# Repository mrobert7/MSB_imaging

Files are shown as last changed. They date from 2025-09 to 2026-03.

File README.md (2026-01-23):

# LOTUS: A low-cost time-lapse automated imaging system for spatio-temporal analysis of microbial colony or biofilm development



## Overview

LOTUS is an open-source automated biofilm imaging platform built using Raspberry Pi, 3D-printed components, and motorized sample positioning. This repository contains all necessary files, scripts, and documentation to build and operate your own LOTUS system for macro-scale bacterial biofilm research.

Published in: *PLOS ONE* - Sakai et al. (2026)

LOTUS provides a cost-effective alternative to expensive commercial imaging systems while maintaining sufficient capability for spatio-temporal analysis of bacterial biofilm development and gene expression dynamics. The system is designed for:

- **Biofilm heterogeneity studies** - Track spatial and temporal patterns in biofilm development
- **Fluorescence reporter imaging** - Monitor gene expression using GFP, mCherry, and other fluorescent proteins
- **Multimode imaging** - Brightfield, transparency (biomass proxy), and fluorescence dual-reporter experiments
- **Time-lapse studies** - Automated long-term imaging with minimal user intervention
- **Educational applications** - Accessible platform for teaching microbiology and bioengineering

## Key Features

- **Low-cost construction:** Build for a fraction of commercial system costs
- **Automated sample positioning:** Motorized stage for multi-sample experiments
- **Fluorescence imaging:** Optimized for common fluorescent reporters (GFP, mCherry)
- **Open-source design:** All hardware designs, software, and analysis tools freely available
- **Validated performance:** Peer-reviewed characterization of sensitivity SNR, channel cross-talk, and phototoxicity
- **Flexible and modular:** Customize for your specific research needs

## Repository Contents

### 📁 [3D_printed_parts_stl_file](./3D_printed_parts_stl_file)
STL files for all custom 3D-printed components including:
- Sample stage
- Camera mounts
- LED housing
- Motorized positioning components

### 📁 [3D_printer_parameter](./3D_printer_parameter)
Recommended printing parameters and settings for optimal part quality and functionality.

### 📁 [Setting up LOTUS](./Setting%20up%20LOTUS)
Complete setup documentation including:
- Hardware assembly instructions
- Raspberry Pi configuration
- Software installation
- System calibration procedures

### 📁 [Experimental_script_imaging_operation](./Experimental_script_imaging_operation)
Python scripts for:
- Automated image acquisition
- Time-lapse control
- Multi-sample positioning
- Fluorescence excitation control

### 📁 [Image_Analysis](./Analysis_imageJ)
ImageJ macros and workflows for:
- Image preprocessing
- Biofilm biomass quantification
- Fluorescence intensity analysis
- Time-series data processing

### 📁 [Supervisor](./Supervisor)
System monitoring and management tools:
- Process supervision
- Automated restart functionality
- Error logging and recovery

### 📁 [Supplementary material_video](./Supplementary%20material_video)
Demonstration videos showing:
- System operation
- Biofilm time-lapse examples
- Setup procedures

## System Capabilities

### Validated Performance Metrics

- **Detection sensitivity:** Quantitative detection of fluorescent reporter expression
- **Temporal resolution:** Configurable image acquisition intervals (minutes to hours)
- **Spatial coverage:** Multiple biofilm colonies per experiment
- **Photobleaching characterization:** Minimal signal degradation over extended imaging
- **Signal-to-noise ratio:** Sufficient for semi-quantitative gene expression analysis
- **Channel cross-talk:** Validated for dual-reporter experiments (GFP/mCherry)
- **Phototoxicity assessment:** Safe for bacterial biofilm viability

## Citation

If you use LOTUS in your research, please cite:

> Sakai, M., et al. (2026). LOTUS: A low-cost open-source automated biofilm imaging system for spatio-temporal analysis of bacterial gene expression. *PLOS ONE*. DOI: [10.1371/journal.pone.0339652](https://journals.plos.org/plosone/article?id=10.1371/journal.pone.0339652)

## Comparison to Commercial Systems

| Feature | LOTUS | Commercial Systems |
|---|---|---|
| Cost | < $550 | $10,000 - $100,000+ |
| Application | Macro-scale screening | Single-cell to macro |
| Resolution | Semi-quantitative | High-resolution quantitative |
| Throughput | Multi-sample (configurable) | Varies |
| Customization | Fully open-source | Limited |
| Best for | Budget-conscious labs, experimenting, education, screening | Detailed mechanistic studies |

LOTUS is designed to **complement** rather than replace commercial systems, providing an accessible entry point for biofilm research.

## Contributing

We welcome contributions from the community! Please consider:

- Reporting bugs or issues
- Suggesting enhancements
- Sharing your modifications or improvements
- Contributing analysis tools or scripts
- Documenting your experiences

Please open an issue or submit a pull request on GitHub.

## Support and Contact

- **Issues:** Use GitHub Issues for bug reports and technical questions
- **Discussions:** Share your experiences and ask questions in GitHub Discussions
- **Email:** [robert.martin.4m@kyoto-u.ac.jp]

## License

You are free to:
- Use LOTUS for academic or commercial purposes
- Modify and distribute the design
- Build upon this work

We only ask that you:
- Provide attribution (cite our paper)
- Share improvements with the community

## Acknowledgments

We thank the open-source hardware community for inspiration and the microbiology research community for valuable feedback during development.

Special thanks to:
- PLOS ONE reviewers for thorough feedback that improved the system
- Colleagues and MSB lab beta testers at Kyoto University who provided validation data
- The Raspberry Pi Foundation for accessible computing platforms

## Additional Resources

- **PLOS ONE publication:** [Link to paper](https://journals.plos.org/plosone/article?id=10.1371/journal.pone.0339652)
- **Supplementary Information:** Detailed validation protocols and additional data
- **Video demonstrations:** See `Supplementary material_video/`
- **Community forum:** [TBA]

---

**LOTUS** - Making biofilm research accessible to all laboratories, regardless of budget.

For questions, collaborations, or to share your LOTUS builds, please reach out!

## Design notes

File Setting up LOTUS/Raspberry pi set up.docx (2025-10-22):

I. Raspberry pi setup
1. Install and launch Raspberry pi imager from web site to your computer

(https://www.raspberrypi.com/software/)

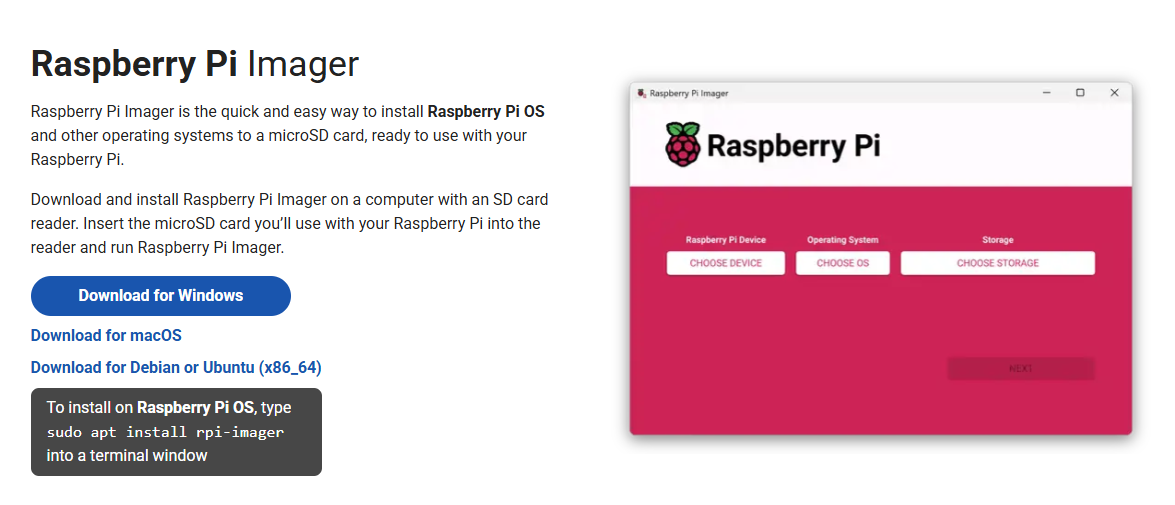
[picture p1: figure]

2. Download Legacy OS (https://downloads.raspberrypi.com/raspios_oldstable_armhf/images/raspios_oldstable_armhf-2024-03-12/) and write Raspberry pi OS (Legacy) to SD card
3. Install SD card to Raspberry pi board
4. Connect keyboard, mouse and display to Raspberry pi board
5. Turn Raspberry pi ON
6. Setup nationality, language, user name, password and wifi connection
7. Shutdown and remove mouse, keyboard and display
8. Turn Raspberry pi ON, When desktop is available, Connect your computer to Raspberry pi remotely using via VNC viewer (Need to enter IP address, user name and password in advance) (Download VNC Viewer by RealVNC® (https://www.realvnc.com/en/connect/download/viewer/?lai_sr=5-9&lai_sl=l))
9. To stabilize network connection, Parameter is change in network preference

Configure : wlan0

□Automatically configure empty option

☑ Disable IPv6

IPv4 Address : Raspberry pi IP address

Please fill the Router, DNS servers and DNS search items.

Check list

□Can you connect to Raspberry pi using VNC?

II. Supervisor application
1. In linux terminal, enter “ sudo apt-get install supervisor “
2. In linux terminal, enter “ cd /etc/supervisor “
3. In linux terminal, enter “ ls “
4. Update permissions for all files listed using “ sudo chmod 777 supervisord.conf “
5. Update permissions for all files listed using “ sudo chmod -R 777 conf.d “
6. Open file manager and enter “ /etc/supervisor “ at directory
7. Rewrite the contents of supervisord.conf to the same context as attached folder and save it. supervisord.conf file directory : " https://github.com/mrobert7/MSB_imaging/blob/main/Supervisor/supervisord.conf "
8. Create a file named “ CU.conf ” in the conf.d folder, paste the contents of the attached CU.conf and save it. (Use the username set on the Raspberry pi.)

CU.conf file directory : " https://github.com/mrobert7/MSB_imaging/blob/main/Supervisor/conf.d/CU.conf "

9. Create a folder in home/pi with the name Experiment and create files in the folder with the names “ CU.py ” and “ CU.log ”.
10. In linux terminal, enter “ pip3 install ischedule “
11. Reboot
12. Check to see if any errors are identified when executing “ sudo supervisorctl status CU:CU.py ” in linux terminal.

Check list

□Is “CU.py” executable in Supervisor?

III. Setup Camera module
1. In linux terminal, enter “ sudo geany “
2. Open boot/config.txt file by geany and write “ dtoverlay=arducam-64mp “ at the bottom of the script in the config.txt file (16mp→imx519)

Please check→ https://docs.arducam.com/Raspberry-Pi-Camera/Native-camera/Quick-Start-Guide/#cm3cm4

3. In linux terminal, enter “ wget -O install_pivariety_pkgs.sh https://github.com/ArduCAM/Arducam-Pivariety-V4L2-Driver/releases/download/install_script/install_pivariety_pkgs.sh “
4. In linux terminal, enter “ chmod +x install_pivariety_pkgs.sh “
5. In linux terminal, enter “ ./install_pivariety_pkgs.sh -p libcamera_dev “
6. In linux terminal, enter “ ./install_pivariety_pkgs.sh -p libcamera_apps “
7. Reboot
8. To check camera operation, in terminal, enter “ libcamera-hello “

(Please check whether camera is accurately connected to pi computer)

Check list

□Is the camera working?

IV. Ready for experiment script
1. Make a “ slotimaging “ folder in the new USB .
2. Make a “ Data “ folder in the “ slotimaging “ folder .
3. Create a “ well1 “ “ well2 ““ well3 ““ well4 ““ well5 ““ well6 ““ well7 ““ well8 ““ well9 “folder in the “ Data “ folder in the USB.
4. Create a “ Data1 “ “ Data2 ““ Data3 ““ Data4 “folder in the each well folder.
5. Download all sh files to Experiment folder

sh file directory : https://github.com/mrobert7/MSB_imaging/tree/main/Experimental_script_imaging_operation "

※Rewrite the contents of sh file to use as an imaging parameter script.

Example (White trans image)

libcamera-still

--width 2312 # Width pixel of captured image

--height 1736 # height pixel of captured image

--datetime -n -o /media/raspberry4/Raspi_USB/slotimaging/well1/Data1 # Directory to destination folder

--contrast 1.0 # Image contrast

--brightness 0.1 # Image brightness

--shutter 500 # Shutter speed (unit is µs)

--autofocus-mode manual # Manual focus

--lens-position 13 # Focus adjustment

--awbgains 1.5,2.0　#RGB

--lens position 14

6. Rewrite contents of “ CU.py “ to the same context as attached folder and save it

※Rewrite the contents of CU.py to use as an experimental script

※Refer to the comment out of the attached CU.py when changing the amount of rotation of the stepping motor and controlling the lighting of the relay module.

CU.py file directory : https://github.com/mrobert7/MSB_imaging/blob/main/Experimental_script_imaging_operation/CU.py

7. When you start taking pictures over time, enter “ sudo supervisorctl start CU:CU.py ” in the linux terminal.
8. When you stop taking pictures over time, enter “ sudo supervisorctl stop CU:CU.py ” in the linux terminal.

List of things to check before starting imaging

□Can you connect and search the net server from Raspberry pi?

□Have you set up your Raspberry pi (contents of this paper)?

□Is the camera working?

□Are the images taken by the camera saved in the specified folder?

□Is the camera in focus?

□Is “CU.py” executable in Supervisor?

□Does the LED array board used light up?

□Are the LEDs controlled to turn on and off via relay modules?

□Is the LED light source and optical filter exchangeable via stepper motors?

□Is the position of the sample for photography controlled correctly by the stepping motor?

□Is the table with the shooting sample in the initial position?

□Is the power supply for the stepping motor and relay module connected (5V)?

□Is the external power supply for the LEDs connected (18V)?

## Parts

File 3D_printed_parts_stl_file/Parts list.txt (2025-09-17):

Parts list

1. Motor box_1.stl×3
2. Motor box_2.stl×3
3. Motor box_3.stl×3
4. Rail.stl×3
5. Rail base.stl
6. Illumination module scaffold.stl
7. Illumination module fixture.stl×3
8. Transilluminator_1.stl
9. Transilluminator_2.stl
10. Transilluminator_3.stl
11. Transilluminator_4.stl
12. Base.stl
13. Filter wheel.stl
14. Filter box cover.stl
15. Separater.stl
16. Sample stage.stl

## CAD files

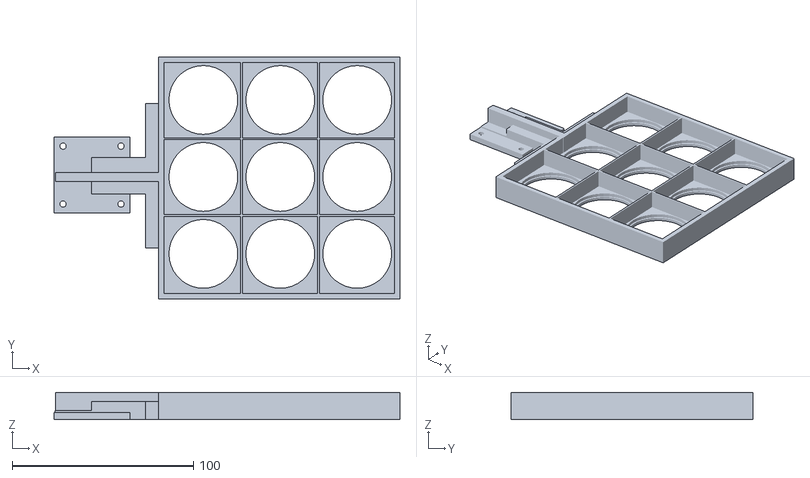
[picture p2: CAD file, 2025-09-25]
3D_printed_parts_stl_file/16. Sample stage.stl
191.1 x 133.6 x 15.0

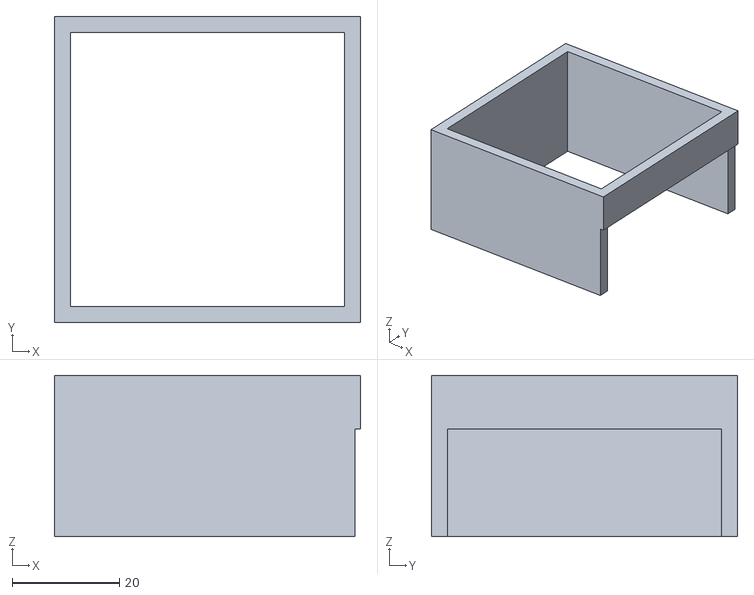
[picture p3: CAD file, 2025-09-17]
3D_printed_parts_stl_file/10. Transilluminator_3.stl
57.0 x 57.0 x 30.0

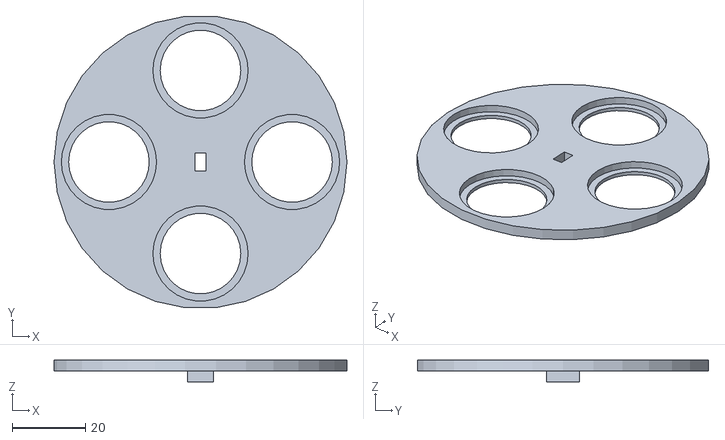
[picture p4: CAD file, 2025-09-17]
3D_printed_parts_stl_file/13. Filter wheel.stl
80.0 x 79.6 x 6.00

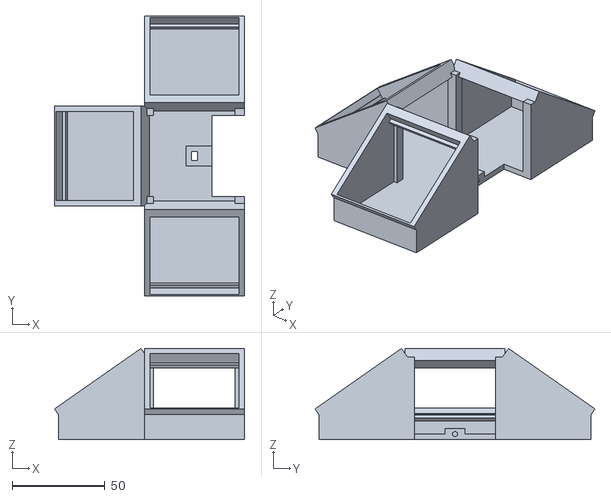
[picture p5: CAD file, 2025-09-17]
3D_printed_parts_stl_file/6. Illumination module scaffold.stl
102.6 x 151.2 x 49.2

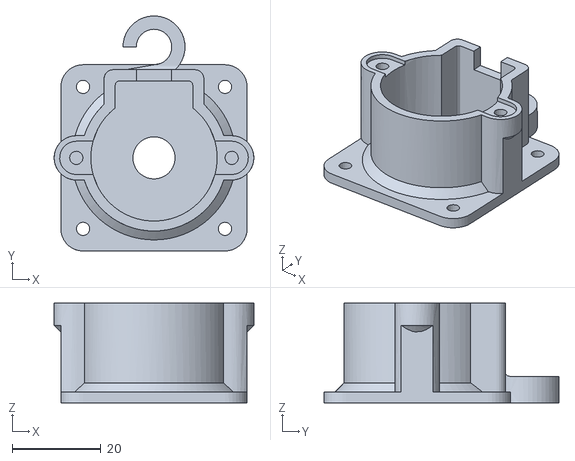
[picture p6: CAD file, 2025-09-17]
3D_printed_parts_stl_file/1. Motor box_1.stl
45.0 x 53.0 x 22.5

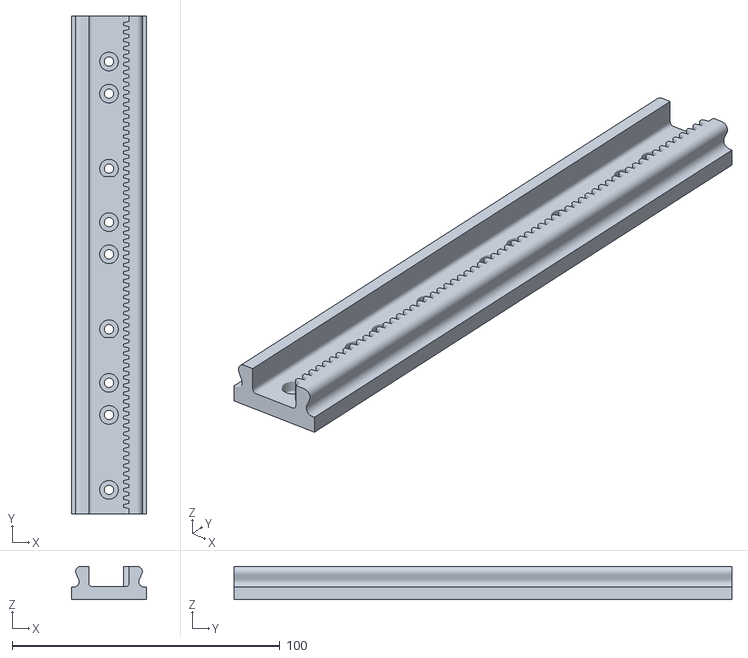
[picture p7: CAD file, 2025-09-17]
3D_printed_parts_stl_file/4. Rail.stl
28.0 x 186.0 x 12.5

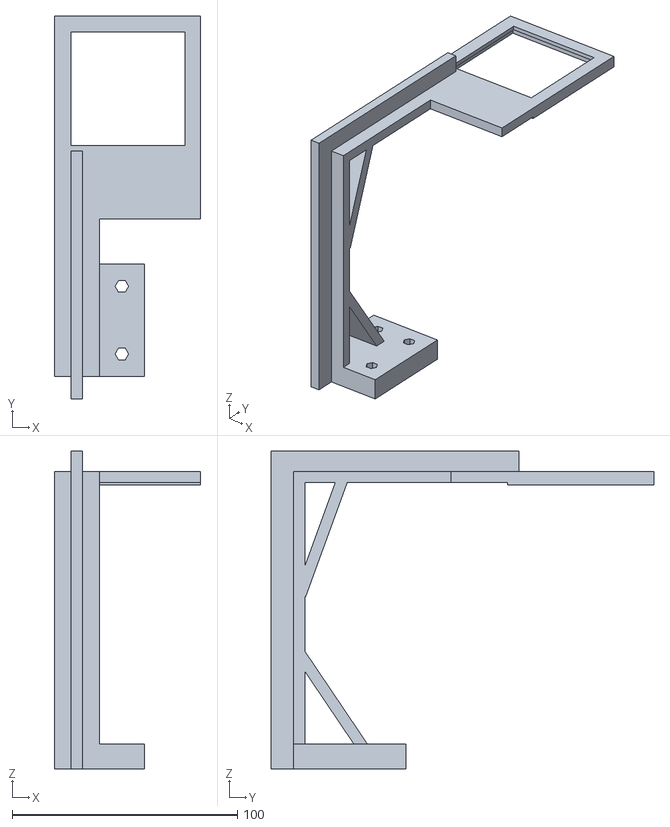
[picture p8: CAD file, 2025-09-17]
3D_printed_parts_stl_file/9. Transilluminator_2.stl
65.0 x 170.0 x 141.0

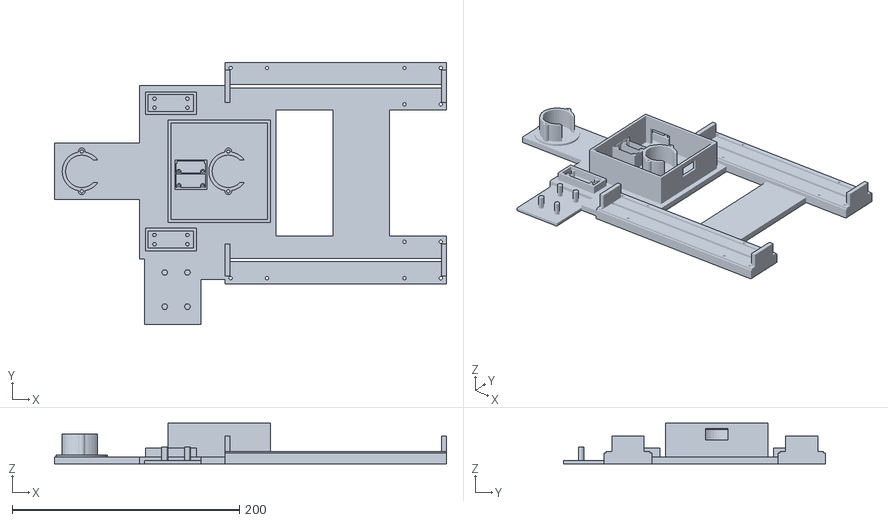
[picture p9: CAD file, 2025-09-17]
3D_printed_parts_stl_file/12. Base.stl
345.0 x 231.0 x 36.0

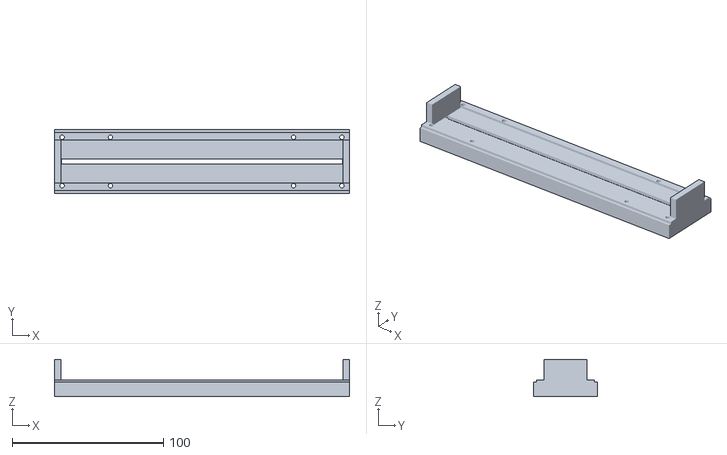
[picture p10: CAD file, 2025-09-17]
3D_printed_parts_stl_file/5. Rail base.stl
195.0 x 42.0 x 24.5

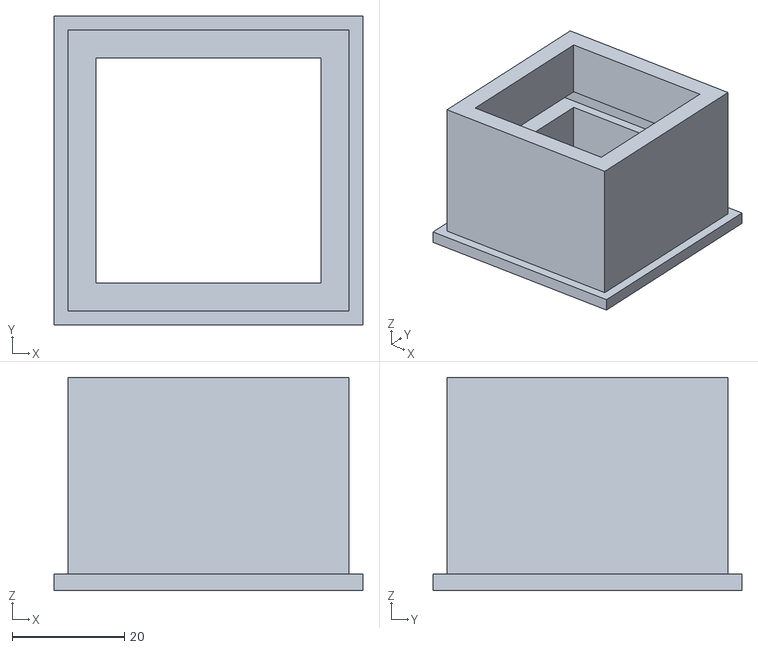
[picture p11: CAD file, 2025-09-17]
3D_printed_parts_stl_file/8. Transilluminator_1.stl
55.0 x 55.0 x 38.0

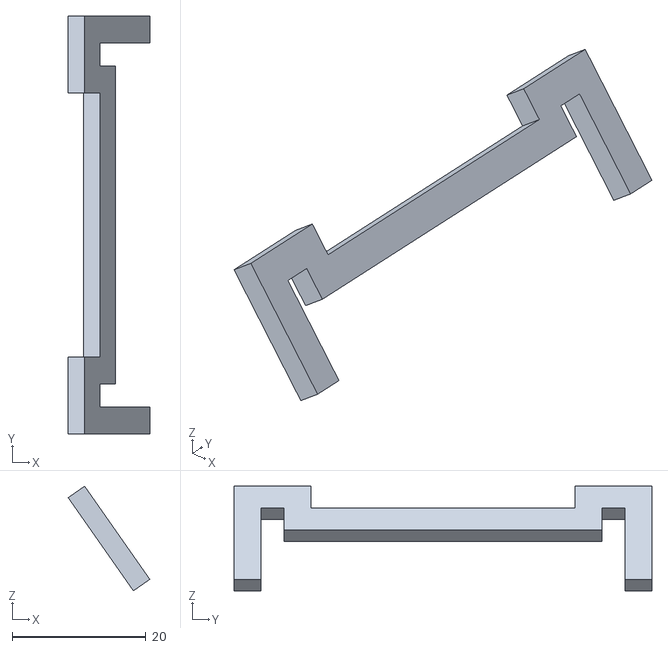
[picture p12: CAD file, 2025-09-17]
3D_printed_parts_stl_file/7. Illumination module fixture.stl
12.2 x 62.5 x 15.6

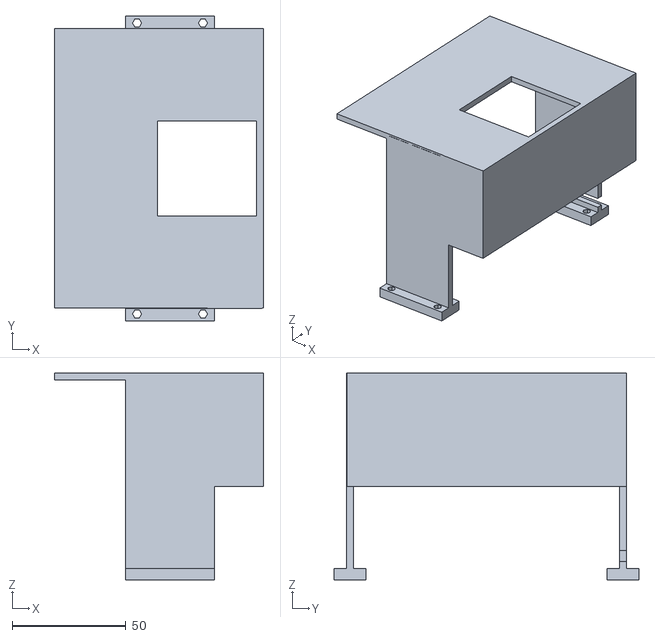
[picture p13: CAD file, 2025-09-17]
3D_printed_parts_stl_file/15. Separater.stl
91.9 x 134.0 x 91.0

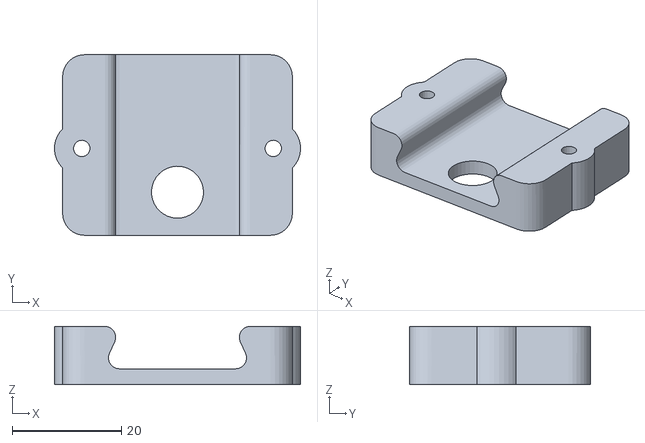
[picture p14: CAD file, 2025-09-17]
3D_printed_parts_stl_file/2. Motor box_2.stl
45.0 x 33.0 x 10.6

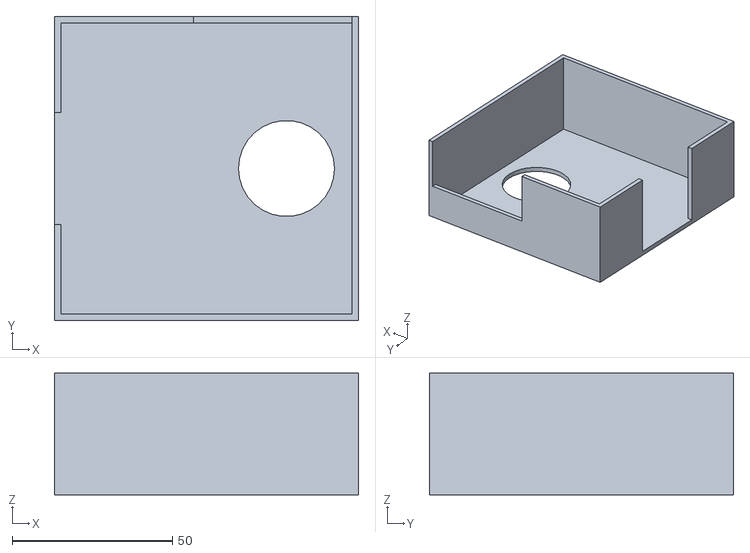
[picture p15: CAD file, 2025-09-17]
3D_printed_parts_stl_file/14. Filter box cover.stl
95.0 x 95.0 x 38.0

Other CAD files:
3D_printed_parts_stl_file/3. Motor box_3.stl
3D_printed_parts_stl_file/11. Transilluminator_4.stl

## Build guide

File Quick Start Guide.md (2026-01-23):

### Prerequisites

**Hardware Requirements:**
- Raspberry Pi (Model 4 recommended, 4GB+ RAM)
- Raspberry Pi Camera Module (HQ Camera or Camera Module v2)
- Stepper motors and drivers for automated positioning
- LEDs for fluorescence excitation (470nm for GFP, 525nm for mCherry)
- 3D printer access for custom components
- Basic electronic components (see detailed parts list)

**Software Requirements:**
- Raspberry Pi OS (Bullseye or newer)
- Python 3.7+
- ImageJ/Fiji for image analysis
- Git for repository access

### Quick Start Guide

1. **Clone this repository:**
   ```bash
   git clone https://github.com/mrobert7/MSB_imaging.git
   cd MSB_imaging
   ```

2. **3D print the components:**
   - Navigate to `3D_printed_parts_stl_file/`
   - Print all STL files using parameters in `3D_printer_parameter/`
   - Recommended: PLA filament

3. **Set up the Raspberry Pi:**
   - Follow instructions in `Setting up LOTUS/`
   - Install required Python packages
   - Configure camera and GPIO pins
   - Test motor controls

4. **Run your first experiment:**
   - Use scripts in `Experimental_script_imaging_operation/`
   - Start with basic brightfield imaging
   - Progress to fluorescence time-lapse experiments

5. **Analyze your data:**
   - Import images into ImageJ
   - Use macros from `Analysis_imageJ/`
   - Process time-series data

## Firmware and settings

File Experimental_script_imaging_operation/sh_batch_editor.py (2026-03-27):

#!/usr/bin/env python3
"""Small GUI to batch-edit libcamera options in .sh files.

Requirements:
- Standard library only (tkinter, pathlib, re)
- Works across common Python 3 versions

Quick setup on a new PC:
1) Install Python 3 (3.8+ recommended)
2) Run this script:
    python sh_batch_editor.py

If tkinter is missing:
- Ubuntu/Debian: sudo apt-get update; sudo apt-get install -y python3-tk
- Fedora: sudo dnf install -y python3-tkinter
- Arch: sudo pacman -S tk
- Windows/macOS: reinstall official Python from python.org and keep Tcl/Tk enabled
"""

from __future__ import annotations

import re
import subprocess
import sys
from pathlib import Path

try:
    import tkinter as tk
    from tkinter import ttk, messagebox, filedialog
except Exception as exc:  # pragma: no cover - startup-only environment check
    msg = (
        "Tkinter is not available in this Python installation.\n\n"
        "Install/fix Tk and run again:\n"
        "- Ubuntu/Debian: sudo apt-get update; sudo apt-get install -y python3-tk\n"
        "- Fedora: sudo dnf install -y python3-tkinter\n"
        "- Arch: sudo pacman -S tk\n"
        "- Windows/macOS: reinstall Python from python.org with Tcl/Tk enabled\n"
    )
    raise SystemExit(msg) from exc


SCRIPT_PATTERN = "test*.sh"
PIP_PACKAGES: tuple[str, ...] = ()
FIRST_RUN_FLAG = Path(__file__).with_name(".sh_batch_editor_first_run_done")
FIRST_RUN_FLAG.exists() or ((subprocess.check_call([sys.executable, "-m", "pip", "install", *PIP_PACKAGES]) if PIP_PACKAGES else True) and FIRST_RUN_FLAG.write_text("done\n", encoding="utf-8"))


def replace_or_add_option(command: str, option: str, value: str) -> str:
    """Replace --option value if present, otherwise append it."""
    pattern = rf"({re.escape(option)}\s+)(\S+)"
    if re.search(pattern, command):
        return re.sub(pattern, rf"\g<1>{value}", command, count=1)
    return f"{command} {option} {value}".strip()


def set_flag(command: str, flag: str, enabled: bool) -> str:
    """Ensure a flag exists (enabled) or is removed (disabled)."""
    flag_pattern = rf"(?<!\S){re.escape(flag)}(?!\S)"
    has_flag = re.search(flag_pattern, command) is not None
    if enabled and not has_flag:
        return f"{command} {flag}".strip()
    if not enabled and has_flag:
        command = re.sub(flag_pattern, "", command)
        command = re.sub(r"\s+", " ", command).strip()
    return command


def update_command_line(command: str, changes: dict[str, object]) -> str:
    """Apply requested parameter changes to a libcamera-still command line."""
    updated = command

    if changes.get("width") is not None:
        updated = replace_or_add_option(updated, "--width", str(changes["width"]))
    if changes.get("height") is not None:
        updated = replace_or_add_option(updated, "--height", str(changes["height"]))
    if changes.get("contrast") is not None:
        updated = replace_or_add_option(updated, "--contrast", str(changes["contrast"]))
    if changes.get("brightness") is not None:
        updated = replace_or_add_option(updated, "--brightness", str(changes["brightness"]))
    if changes.get("shutter") is not None:
        updated = replace_or_add_option(updated, "--shutter", str(changes["shutter"]))
    if changes.get("denoise") is not None:
        updated = replace_or_add_option(updated, "--denoise", str(changes["denoise"]))
    if changes.get("awbgains") is not None:
        updated = replace_or_add_option(updated, "--awbgains", str(changes["awbgains"]))
    if changes.get("output") is not None:
        updated = replace_or_add_option(updated, "-o", str(changes["output"]))

    if changes.get("datetime") is not None:
        updated = set_flag(updated, "--datetime", bool(changes["datetime"]))
    if changes.get("no_preview") is not None:
        updated = set_flag(updated, "-n", bool(changes["no_preview"]))

    return re.sub(r"\s+", " ", updated).strip()


class ParameterRow:
    def __init__(
        self,
        parent: tk.Widget,
        row: int,
        name: str,
        default: str = "",
        on_toggle=None,
        on_commit=None,
    ) -> None:
        self.enabled_var = tk.BooleanVar(value=False)
        self.value_var = tk.StringVar(value=default)

        ttk.Checkbutton(parent, text=name, variable=self.enabled_var, command=on_toggle).grid(
            row=row, column=0, sticky="w", padx=(0, 8), pady=2
        )
        self.entry = ttk.Entry(parent, textvariable=self.value_var, width=22)
        self.entry.grid(row=row, column=1, sticky="ew", pady=2)
        self.entry.bind("<FocusOut>", lambda _e: on_commit() if on_commit else None)
        self.entry.bind("<Return>", lambda _e: on_commit() if on_commit else None)


class ChoiceRow:
    def __init__(
        self,
        parent: tk.Widget,
        row: int,
        name: str,
        choices: list[str],
        default: str,
        on_toggle=None,
        on_commit=None,
    ) -> None:
        self.enabled_var = tk.BooleanVar(value=False)
        self.value_var = tk.StringVar(value=default)

        ttk.Checkbutton(parent, text=name, variable=self.enabled_var, command=on_toggle).grid(
            row=row, column=0, sticky="w", padx=(0, 8), pady=2
        )
        self.combo = ttk.Combobox(
            parent,
            textvariable=self.value_var,
            values=choices,
            state="readonly",
            width=20,
        )
        self.combo.grid(row=row, column=1, sticky="ew", pady=2)
        self.combo.bind("<<ComboboxSelected>>", lambda _e: on_commit() if on_commit else None)


class App(tk.Tk):
    def __init__(self) -> None:
        super().__init__()
        self.title("SH Batch Editor")
        self.geometry("860x560")
        self.minsize(760, 500)

        self.script_dir = Path(__file__).resolve().parent
        self.base_dir = self.script_dir
        self.files = sorted(self.base_dir.glob(SCRIPT_PATTERN))

        self._build_ui()
        self._load_files()

    def _build_ui(self) -> None:
        main = ttk.Frame(self, padding=10)
        main.pack(fill="both", expand=True)
        main.columnconfigure(0, weight=1)
        main.columnconfigure(1, weight=1)

        left = ttk.LabelFrame(main, text="Shell Scripts", padding=8)
        left.grid(row=0, column=0, sticky="nsew", padx=(0, 8))
        left.rowconfigure(1, weight=1)
        left.columnconfigure(0, weight=1)

        dir_row = ttk.Frame(left)
        dir_row.grid(row=0, column=0, sticky="ew", pady=(0, 6))
        dir_row.columnconfigure(0, weight=1)

        self.target_dir_var = tk.StringVar(value=str(self.base_dir))
        ttk.Entry(dir_row, textvariable=self.target_dir_var).grid(row=0, column=0, sticky="ew")
        ttk.Button(dir_row, text="Set", command=self._set_folder_from_entry).grid(row=0, column=1, padx=(6, 0))
        ttk.Button(dir_row, text="Browse", command=self._browse_folder).grid(row=0, column=2, padx=(6, 0))
        ttk.Button(dir_row, text="Script Folder", command=self._use_script_folder).grid(row=0, column=3, padx=(6, 0))

        self.file_list = tk.Listbox(left, selectmode=tk.EXTENDED, exportselection=False)
        self.file_list.grid(row=1, column=0, sticky="nsew")

        btn_row = ttk.Frame(left)
        btn_row.grid(row=2, column=0, sticky="ew", pady=(8, 0))
        ttk.Button(btn_row, text="Select All", command=self._select_all).pack(side="left")
        ttk.Button(btn_row, text="Clear", command=self._clear_selection).pack(side="left", padx=(8, 0))
        ttk.Button(btn_row, text="Refresh", command=self._refresh_files).pack(side="left", padx=(8, 0))
        ttk.Button(btn_row, text="Apply All Files", command=self.apply_changes_all_files).pack(side="left", padx=(8, 0))

        right = ttk.LabelFrame(main, text="Parameters To Edit", padding=8)
        right.grid(row=0, column=1, sticky="nsew")
        right.columnconfigure(1, weight=1)

        self.rows: dict[str, object] = {}
        line = 0
        self.rows["width"] = ParameterRow(right, line, "--width", "2312", on_toggle=self._on_param_toggled, on_commit=self._auto_apply_if_enabled)
        line += 1
        self.rows["height"] = ParameterRow(right, line, "--height", "1736", on_toggle=self._on_param_toggled, on_commit=self._auto_apply_if_enabled)
        line += 1
        self.rows["contrast"] = ParameterRow(right, line, "--contrast", "1.0", on_toggle=self._on_param_toggled, on_commit=self._auto_apply_if_enabled)
        line += 1
        self.rows["brightness"] = ParameterRow(right, line, "--brightness", "0.1", on_toggle=self._on_param_toggled, on_commit=self._auto_apply_if_enabled)
        line += 1
        self.rows["shutter"] = ParameterRow(right, line, "--shutter", "500", on_toggle=self._on_param_toggled, on_commit=self._auto_apply_if_enabled)
        line += 1
        self.rows["denoise"] = ChoiceRow(
            right,
            line,
            "--denoise",
            ["off", "auto", "cdn_off", "cdn_fast", "cdn_hq"],
            "off",
            on_toggle=self._on_param_toggled,
            on_commit=self._auto_apply_if_enabled,
        )
        line += 1
        self.rows["awbgains"] = ParameterRow(right, line, "--awbgains", "1.5,2.0", on_toggle=self._on_param_toggled, on_commit=self._auto_apply_if_enabled)
        line += 1
        self.rows["output"] = ParameterRow(
            right,
            line,
            "-o output path",
            "/media/raspberry4/Raspi_USB/slotimaging/well1/Data1",
            on_toggle=self._on_param_toggled,
            on_commit=self._auto_apply_if_enabled,
        )
        line += 1
        self.rows["datetime"] = ChoiceRow(
            right,
            line,
            "--datetime",
            ["on", "off"],
            "on",
            on_toggle=self._on_param_toggled,
            on_commit=self._auto_apply_if_enabled,
        )
        line += 1
        self.rows["no_preview"] = ChoiceRow(
            right,
            line,
            "-n no preview",
            ["on", "off"],
            "on",
            on_toggle=self._on_param_toggled,
            on_commit=self._auto_apply_if_enabled,
        )

        param_btns = ttk.Frame(right)
        param_btns.grid(row=line + 1, column=0, columnspan=2, sticky="ew", pady=(8, 0))
        ttk.Button(param_btns, text="Enable All Params", command=self._enable_all_params).pack(side="left")
        ttk.Button(param_btns, text="Disable All Params", command=self._disable_all_params).pack(side="left", padx=(8, 0))

        action = ttk.Frame(main)
        action.grid(row=1, column=0, columnspan=2, sticky="ew", pady=(10, 0))
        action.columnconfigure(0, weight=1)

        self.auto_write_var = tk.BooleanVar(value=True)
        ttk.Checkbutton(action, text="Auto write on edit", variable=self.auto_write_var).pack(side="left")
        ttk.Button(action, text="Apply To Selected Files", command=self.apply_changes).pack(side="right")

        self.status_var = tk.StringVar(value="Ready")
        ttk.Label(self, textvariable=self.status_var, anchor="w", padding=(10, 0, 10, 10)).pack(fill="x")

    def _load_files(self) -> None:
        self.file_list.delete(0, tk.END)
        for path in self.files:
            self.file_list.insert(tk.END, path.name)
        self.status_var.set(f"Found {len(self.files)} .sh files")

    def _refresh_files(self) -> None:
        self.files = sorted(self.base_dir.glob(SCRIPT_PATTERN))
        self._load_files()

    def _set_folder_from_entry(self) -> None:
        target = Path(self.target_dir_var.get().strip()).expanduser()
        if not target.is_dir():
            messagebox.showerror("Invalid folder", f"Folder not found:\n{target}")
            return
        self.base_dir = target
        self._refresh_files()

    def _browse_folder(self) -> None:
        chosen = filedialog.askdirectory(initialdir=str(self.base_dir))
        if not chosen:
            return
        self.target_dir_var.set(chosen)
        self._set_folder_from_entry()

    def _use_script_folder(self) -> None:
        self.base_dir = self.script_dir
        self.target_dir_var.set(str(self.script_dir))
        self._refresh_files()

    def _select_all(self) -> None:
        self.file_list.selection_set(0, tk.END)

    def _clear_selection(self) -> None:
        self.file_list.selection_clear(0, tk.END)

    def _enable_all_params(self) -> None:
        for row in self.rows.values():
            row.enabled_var.set(True)
        self._auto_apply_if_enabled()

    def _disable_all_params(self) -> None:
        for row in self.rows.values():
            row.enabled_var.set(False)

    def _on_param_toggled(self) -> None:
        self._auto_apply_if_enabled()

    def _auto_apply_if_enabled(self) -> None:
        if self.auto_write_var.get():
            self.apply_changes(show_dialog=False)

    def _collect_changes(self) -> dict[str, object]:
        changes: dict[str, object] = {}
        for key, row in self.rows.items():
            enabled = row.enabled_var.get()
            if not enabled:
                continue

            value = row.value_var.get().strip()
            if key in {"datetime", "no_preview"}:
                changes[key] = value.lower() == "on"
            else:
                if value == "":
                    raise ValueError(f"Value for {key} is empty")
                changes[key] = value
        return changes

    def _selected_paths(self) -> list[Path]:
        indexes = self.file_list.curselection()
        return [self.files[i] for i in indexes]

    def apply_changes(self, show_dialog: bool = True, use_all_files: bool = False) -> None:
        selected = self.files if use_all_files else self._selected_paths()
        if not selected:
            if show_dialog:
                messagebox.showwarning("No selection", "Select at least one .sh file.")
            else:
                self.status_var.set("No file selection for auto write")
            return

        try:
            changes = self._collect_changes()
        except ValueError as exc:
            if show_dialog:
                messagebox.showerror("Invalid input", str(exc))
            else:
                self.status_var.set(f"Invalid input: {exc}")
            return

        if not changes:
            if show_dialog:
                messagebox.showwarning("No parameters", "Enable at least one parameter to edit.")
            else:
                self.status_var.set("No enabled parameters")
            return

        updated_count = 0
        unchanged_count = 0
        missing_line_count = 0

        for path in selected:
            content = path.read_text(encoding="utf-8")
            lines = content.splitlines()

            command_index = None
            for i, line in enumerate(lines):
                if line.strip().startswith("libcamera-still"):
                    command_index = i
                    break

            if command_index is None:
                missing_line_count += 1
                continue

            old_line = lines[command_index].strip()
            new_line = update_command_line(old_line, changes)

            if old_line == new_line:
                unchanged_count += 1
                continue

            lines[command_index] = new_line
            path.write_text("\n".join(lines) + "\n", encoding="utf-8")
            updated_count += 1

        self.status_var.set(
            f"Updated: {updated_count}, unchanged: {unchanged_count}, no libcamera line: {missing_line_count}"
        )
        if show_dialog:
            messagebox.showinfo(
                "Done",
                (
                    f"Updated: {updated_count}\n"
                    f"Unchanged: {unchanged_count}\n"
                    f"No libcamera-still line: {missing_line_count}"
                ),
            )

    def apply_changes_all_files(self) -> None:
        self.apply_changes(show_dialog=True, use_all_files=True)


def main() -> None:
    app = App()
    app.mainloop()


if __name__ == "__main__":
    main()

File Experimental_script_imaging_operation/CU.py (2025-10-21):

import RPi.GPIO as GPIO
from time import sleep
import datetime
from ischedule import schedule, run_loop
import os
import sys

#Define which GPIO pin controls which relay module
Relaymodule_white = 14
Relaymodule_blue = 15
Relaymodule_green = 18
Relaymodule_white_tra =23 
 

#Define which GPIO pin controls which stepping motor
#If you do not want to synchronize the movement of filters and light sources, prepare scripts for the filter table and the light source table.
motorGpio_low_actuator = (12, 16, 20, 21)     
motorGpio_high_actuator = (24, 25, 8, 7)      
motorGpio_filter_light = (4, 17, 27, 22)      


rightRotation = (0x08,0x04,0x02,0x01)  #Definition of right rotation 
leftRotation = (0x01,0x02,0x04,0x08)   #Definition of left rotation
 
#Set up GPIO pins to drive relay modules and stepper motors
#If you do not want to synchronize the movement of filters and light sources, prepare scripts for the filter table and the light source table.
def setup():
    GPIO.setmode(GPIO.BCM)      
    for pin in motorGpio_low_actuator:
        GPIO.setup(pin,GPIO.OUT)
    for pin in motorGpio_high_actuator:
        GPIO.setup(pin,GPIO.OUT)
    for pin in motorGpio_filter_light:
        GPIO.setup(pin,GPIO.OUT)

    GPIO.setup(Relaymodule_white, GPIO.OUT)
    GPIO.setup(Relaymodule_blue, GPIO.OUT)
    GPIO.setup(Relaymodule_green, GPIO.OUT)
    GPIO.setup(Relaymodule_white_tra, GPIO.OUT)
 
#Define parameters for running the stepping motors (for y axis actuator)
def moveSteps_low(lrset, ms, steps):
    for i in range(steps):
        moveOnePeriod_low(lrset, ms)

#Define parameters for running the stepping motors (for x axis actuator)       
def moveSteps_high(lrset, ms, steps): 
    for i in range(steps):
        moveOnePeriod_high(lrset, ms)

#Define parameters for running the stepping motors (for Light source table and optical filter table)  
#If you do not want to synchronize the movement of filters and light sources, prepare scripts for the filter table and the light source table.       
def moveSteps_filter_light(lrset, ms, steps):
    for i in range(steps):
        moveOnePeriod_filter_light(lrset, ms)

#Definition of GPIO pin inputs and outputs to drive a stepper motor (for x axis actuator)
def moveOnePeriod_low(lrset, ms):
    for j in range(0, 4, 1):
        for i in range(0, 4, 1):
            if lrset == 1:
                GPIO.output(motorGpio_low_actuator[i], ((leftRotation[j] == 1 << i) and GPIO.HIGH or GPIO.LOW))
            else:
                GPIO.output(motorGpio_low_actuator[i], ((rightRotation[j] == 1 << i) and GPIO.HIGH or GPIO.LOW))
        if ms < 2:  #Set to 2 ms if less than 2 ms, since 1 ms will not work.
            ms = 2
        sleep(ms * 0.001)
        
#Definition of GPIO pin inputs and outputs to drive a stepper motor (for y axis actuator)
def moveOnePeriod_high(lrset, ms):
    for j in range(0, 4, 1):
        for i in range(0, 4, 1):
            if lrset == 1:
                GPIO.output(motorGpio_high_actuator[i], ((leftRotation[j] == 1 << i) and GPIO.HIGH or GPIO.LOW))
            else:
                GPIO.output(motorGpio_high_actuator[i], ((rightRotation[j] == 1 << i) and GPIO.HIGH or GPIO.LOW))
        if ms < 2:  #Set to 2 ms if less than 2 ms, since 1 ms will not work.
            ms = 2
        sleep(ms * 0.001)
        
#Definition of GPIO pin inputs and outputs to drive a stepper motor (for Light source table and optical filter table)
#If you do not want to synchronize the movement of filters and light sources, prepare scripts for the filter table and the light source table.
def moveOnePeriod_filter_light(lrset, ms):
    for j in range(0, 4, 1):
        for i in range(0, 4, 1):
            if lrset == 1:
                GPIO.output(motorGpio_filter_light[i], ((leftRotation[j] == 1 << i) and GPIO.HIGH or GPIO.LOW))
            else:
                GPIO.output(motorGpio_filter_light[i], ((rightRotation[j] == 1 << i) and GPIO.HIGH or GPIO.LOW))
        if ms < 2:  #Set to 2 ms if less than 2 ms, since 1 ms will not work.
            ms = 2
        sleep(ms * 0.001)


 
#End processing
def end():
    GPIO.cleanup()   #Clear GPIO. If you don't put it on, you'll get a warning.


#About 0.7°/step
#128 steps = shaft rotates 90°
#Parameter of stepping motor(Rotation direction 0 (left) or 1 (right),Rotation speed,Steps)

#Code sample for imaging 1 well 

    #Trans-illumination white 

    #GPIO.output(Relaymodule_white_tra, GPIO.HIGH)  #Turning on LED
    #sleep(3)   #Holds still for 3 seconds while lit
    #os.system("/home/raspberry4/Experiment/test1_1.sh")    #Capture image (Directory indicates path to sh file)
    #GPIO.output(Relaymodule_white_tra, GPIO.LOW)   #Turning off LED
    #sleep(3)

    #Epi-illumination blue 

    #moveSteps_filter_light(1,3,128)    #Rotate the light source table and optical filter table 90°.
    #GPIO.output(Relaymodule_blue, GPIO.HIGH)
    #sleep(3)
    #os.system("/home/raspberry4/Experiment/test2_1.sh")
    #GPIO.output(Relaymodule_blue, GPIO.LOW)
    #sleep(3)

    #Epi-illumination green 

    #moveSteps_filter_light(1,3,128)    #Rotate the light source table and optical filter table 90°.
    #GPIO.output(Relaymodule_green, GPIO.HIGH)
    #sleep(3)
    #os.system("/home/raspberry4/Experiment/test3_1.sh")
    #GPIO.output(Relaymodule_green, GPIO.LOW)
    #sleep(3)

    #Epi-illumination white
    
    #moveSteps_filter_light(0,3,256)    #Rotate the light source table and optical filter table 180° in opposite directions and return them to their original positions
    #GPIO.output(Relaymodule_white, GPIO.HIGH)
    #sleep(3)
    #os.system("/home/raspberry4/Experiment/test4_1.sh")
    #GPIO.output(Relaymodule_white, GPIO.LOW)
    #sleep(3)
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
